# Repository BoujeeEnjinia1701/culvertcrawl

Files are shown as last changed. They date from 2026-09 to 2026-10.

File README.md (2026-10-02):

# CulvertCrawl

     

**Area:** Situational Field Hardware · **TRL:** 3 of 9 (proof of concept on paper) · **Value-engineering target:** $910 USD · **Difficulty:** 4 of 5

Tethered tracked crawler with a camera, lights and laser ring profiling that measures pipe deformation and blockage.

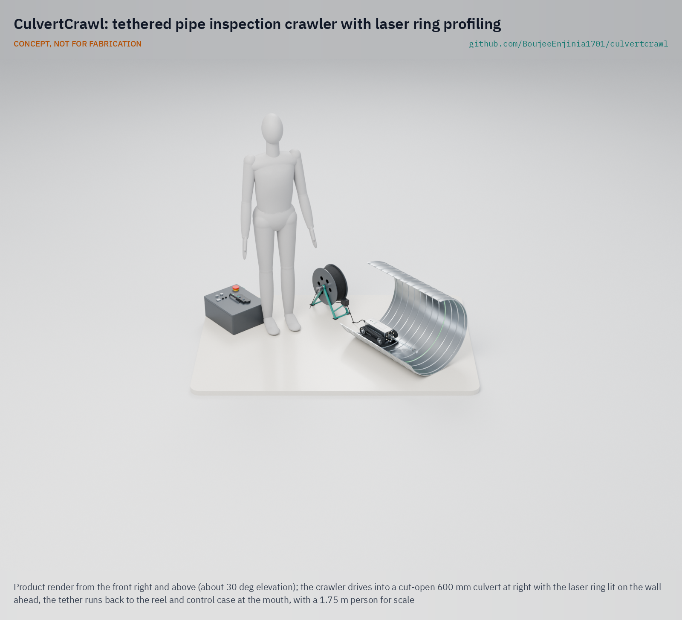
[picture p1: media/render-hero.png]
CulvertCrawl: tethered pipe inspection crawler with laser ring profiling, product render


[Exploded render](media/render-exploded.png) · [Detail render](media/render-detail.png) · [Interactive 3D model](media/viewer.html) · [Concept blueprint (PDF)](media/concept-blueprint.pdf) · [General arrangement (PDF)](cad/drawings/CVC-DWG-001.pdf) · [Calculations](docs/04-calcs/01-sizing.md) · [Prototype build plan](docs/05-build-plan.md) · [Design decisions](docs/06-design-decisions.md) · [Review note](docs/REVIEW.md)

## Concept rationale

A small tracked crawler on a surface-powered tether is the simplest way to see and measure the middle of a pipe that nobody should enter. Putting the battery, the power conversion and the processing at the surface keeps the vehicle small, cool and free of lithium cells, and a projected laser ring turns ordinary video into a cross-section measurement, which is the number owners and inspectors actually need for deflection, sag and sediment. Commercial crawlers already prove the principle; what is missing is a version priced and documented for the road crews, small towns and watershed groups who own most small culverts.

Open hardware fits that gap. Every part is a hobby or industrial catalog item, a machined box or a plate a local shop can cut, so a county shop or a student team can build, seal and repair it, and the video, profiles and observation logs use open formats that feed existing defect-coding practice. At TRL 3 this is a paper design checked by calculation; it is not yet a tested inspection tool.

## Burning platform

Flooding reaches road networks through their drainage. A World Bank global assessment of 2,564 cities in 177 countries found that a 1-in-100-year flood directly exposes 14.7 % of urban roads, yet causes 44.8 % of simulated trips to fail as the damage cascades through the network ([He, Rentschler and Avner, World Bank, 2022](https://blogs.worldbank.org/en/developmenttalk/mobility-and-resilience-global-assessment-flood-impacts-urban-road-networks)). Culverts are among the small, buried links in those networks, and their condition is hard to see from outside.

Public money is now flowing into culverts faster than owners can survey them. The United States set aside $200 million a year for fiscal years 2022 to 2026, $1 billion in all, for the National Culvert Removal, Replacement, and Restoration Grant program ([FHWA](https://highways.dot.gov/iija/fact-sheets/national-culvert-removal-replacement-and-restoration-grants-culvert-aop-program)). In Washington State alone, a federal court injunction issued in March 2013 requires the state to correct fish-barrier culverts under its highways; by June 2026 WSDOT had corrected 200 of them and reopened 705 miles (about 1,130 km) of salmon and steelhead habitat, with more funding still needed ([WSDOT](https://wsdot.wa.gov/construction-planning/protecting-environment/fish-passage/federal-court-injunction-fish-passage)). Choosing which pipes to fix first depends on knowing their condition.

## Where it could be used

### By industry

| Industry | Use |
| --- | --- |
| Road and highway maintenance | Check cross-drain and driveway culverts before resurfacing, after floods and when a sinkhole appears |
| Municipal stormwater | Inventory the condition of small storm drains and outfalls to plan replacements |
| Civil construction quality assurance | Measure deflection of newly installed plastic pipe before a road is paved over it |
| Environmental and fisheries surveys | Look for blockages, perched outlets and internal barriers in fish-passage culverts |
| Rail, forestry and farm roads | Inspect the many small culverts under tracks, logging roads and field access routes |
| Engineering education | An open platform for teaching robotics, sealing, optics and inspection practice |

### By country or region

| Country or region | Why it matters there |
| --- | --- |
| United States | Florida DOT requires laser-profile video inspection of new pipe of 48 in or less and replaces pipe deflected 5 % or more ([FDOT Section 430](https://fdotwww.blob.core.windows.net/sitefinity/docs/default-source/specifications/by-year/2008/july-2008/workbook/ss4300000.pdf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)); Washington State is correcting fish-barrier culverts under a federal injunction ([WSDOT](https://wsdot.wa.gov/construction-planning/protecting-environment/fish-passage/federal-court-injunction-fish-passage)) |
| United Kingdom | More than one million culverts and outfalls, which can completely restrict flow, are often costly to maintain and need ongoing assessment for sedimentation and blockage ([CIRIA and Environment Agency, *Culvert, screen and outfall manual*, via GOV.UK](https://www.gov.uk/flood-and-coastal-erosion-risk-management-research-reports/culvert-screens-and-outfall-manual)); councils such as Devon note that culverting can worsen flood risk and raise maintenance needs ([Devon County Council](https://www.devon.gov.uk/floodriskmanagement/land-drainage-consent/culvert-guidance/)) |
| Cambodia and Southeast Asia | The World Bank and GFDRR support climate-resilient rural road programs because flooded rural roads cut critical access for rural communities ([GFDRR](https://www.gfdrr.org/en/feature-story/pathway-resilient-rural-roads-cambodia)) |
| India | About 783,700 km of rural road had been completed under the Pradhan Mantri Gram Sadak Yojana by August 2025, and contractors are now paid for maintenance on the condition of each road's cross-drainage works among other assets ([Press Information Bureau, Government of India](https://static.pib.gov.in/WriteReadData/specificdocs/documents/2025/sep/doc2025914636101.pdf)) |
| Mali and Sudan | The World Bank global assessment found that more than half of simulated urban trips fail in these countries even in floods of lower intensity, so small drainage links matter early ([World Bank, 2022](https://blogs.worldbank.org/en/developmenttalk/mobility-and-resilience-global-assessment-flood-impacts-urban-road-networks)) |

## What sparked the idea

The starting point was a construction specification. Since at least 2008 the Florida Department of Transportation's Standard Specifications, Section 430, have required contractors to inspect newly installed pipe of 48 in (1,200 mm) or less with "low barrel distortion video equipment with laser profile technology," to report deflection and diameter, and to replace pipe deflected 5 % or more ([FDOT Section 430, Rev 12-7-07](https://fdotwww.blob.core.windows.net/sitefinity/docs/default-source/specifications/by-year/2008/july-2008/workbook/ss4300000.pdf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)). The same clause lets the engineer waive the requirement for side drains and cross drains short enough to inspect from each end. That pairing shows both halves of the design: laser ring profiling is already the accepted way to measure a buried pipe, while short culverts, and the older pipes that no contract covers, are still judged from the ends. CulvertCrawl aims to put that measurement within reach of the crews who look after those pipes for the rest of their service lives.

## Problem

Small culverts and drains are hard to inspect without confined-space entry. Pipes of 300 to 900 mm (12 to 36 in) are too small or too hazardous to walk through, so most are judged from the ends, and commercial CCTV crawlers are priced for sewer contractors, not the road crews and small owners who look after most culverts.

Problem statement: [docs/01-problem.md](docs/01-problem.md)

## Concept

Tethered tracked crawler with a camera, lights and laser ring profiling that measures pipe deformation and blockage. A 6.6 kg crawler drives into the pipe on a 60 m tether carrying 48 V DC and Ethernet; a laser ring projected 300 mm ahead of a fisheye camera gives a cross-section every 6 mm, from which the operator's laptop reports diameter, ovality and sediment depth against distance. The first output is a deflection report; observations are logged in NASSCO PACP vocabulary, and FHWA condition ratings come later. The TRL 3 calculations ([CVC-CAL-001](docs/04-calcs/01-sizing.md)) give 6.4 h per charge, about 75 m of reach driving uphill in a flooded pipe, and profile accuracy within 1 % of diameter from 300 to 900 mm (0.97 % at 900 mm, a thin margin). The wet reach depends on track friction under water, which only a test can settle. All figures are calculated estimates.

Full design precis: [docs/02-concept.md](docs/02-concept.md) · Requirements: [docs/03-requirements.md](docs/03-requirements.md) · Calculations: [docs/04-calcs/01-sizing.md](docs/04-calcs/01-sizing.md) · General arrangement: [cad/drawings/CVC-DWG-001.pdf](cad/drawings/CVC-DWG-001.pdf) · Model: [cad/src/model.py](cad/src/model.py)

## Key components

- Sealed aluminium hull with tracked chassis
- Self-locking worm gear motors (2)
- Waterproof fisheye camera behind a dome port
- LED ring light
- Class 2 laser ring projector (laser diode and conical mirror)
- 60 m hybrid tether on a reel with slip ring and payout counter
- Raspberry Pi 4 in the crawler
- Surface control box with LiFePO4 battery, 48 V boost and emergency stop

The priced bill of materials is in [bom/bom.csv](bom/bom.csv). Value-engineering target: $910 (a hypothetical control target, not a limit). Estimated cost of the constructable design: $1,034 ($124 over the target), because the parts that make the design buildable added $128. Cost drivers and savings worth trying are in the [design decisions register](docs/06-design-decisions.md).

## Building the prototype

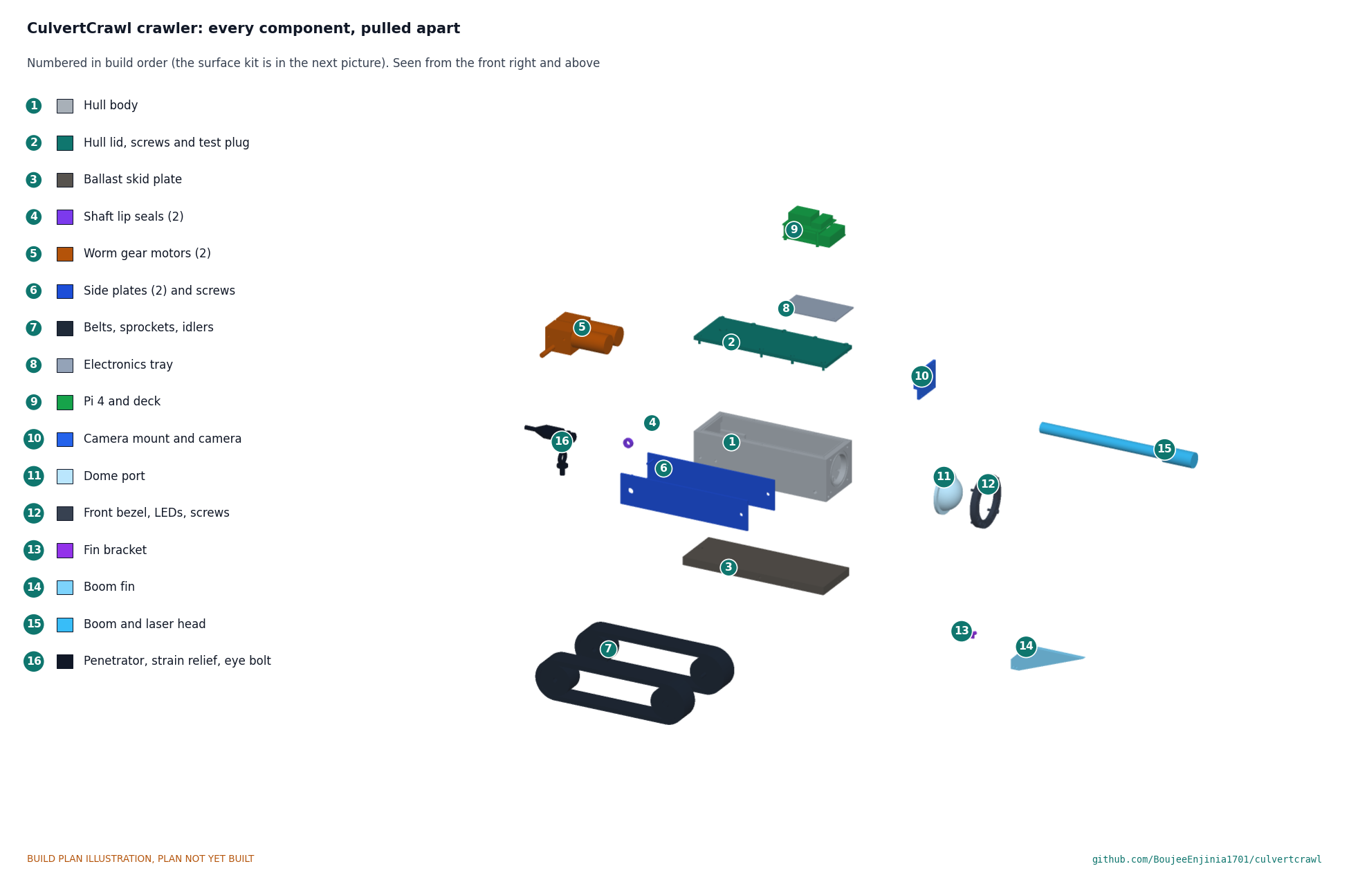
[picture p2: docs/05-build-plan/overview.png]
CulvertCrawl crawler: every component pulled apart and numbered in build order


The [prototype build plan](docs/05-build-plan.md) (CVC-BLD-001) shows, in pictures, how to make each component of the crawler, the tether reel and the surface box and put them together in 23 steps; nothing has been built yet. The hull, lid and front bezel are machined aluminium, the ballast plate is cut steel, the side plates, brackets, reel frames and box panel are cut from sheet and bar, the laser boom, fin and window are clear acrylic, and the motors, tracks, camera, electronics, tether and slip ring are bought. Writing the plan made the design buildable: a rim and pads inside the hull, side plates that tie the hull to the ballast plate, a bezel that clamps the dome, a fin that carries the laser boom, an eye bolt for the tether's strength member, a reel frame with bearings and a drop-in chassis for the surface box (CVC-DDR-003, open for Amish's review). Every picture is drawn from the model, and the model checks that each part touches what it should and clears what it should not.

## Repository layout

| Folder | Contents |
| --- | --- |
| `docs/` | Problem, concept, requirements, calculations and design decisions |
| `cad/src/` | build123d Python source, the source of truth for all geometry |
| `cad/step/`, `cad/stl/` | Exported models for FreeCAD, other CAD tools and printing |
| `cad/drawings/` | 2D sketches and dimensioned drawings |
| `bom/` | Bill of materials |
| `electronics/` | KiCad schematics and PCB layouts |
| `firmware/` | Microcontroller code |
| `media/` | Renders, perspectives and photos |
| `build-log/` | Dated prototyping notes |

## Documentation

Controlled documents follow the portfolio [documentation standard](.kit/STANDARDS.md). Each carries a document ID (CVC-PRC-001 for the precis), a version and a revision history. Branded PDFs are built with `python .kit/render.py` and attached to GitHub Releases when a document is tagged, for example `CVC-PRC-001/v1.0`.

## Credits

Designed by Amish Chadha. See [CONTRIBUTORS.md](CONTRIBUTORS.md) for roles. To cite this design, use [CITATION.cff](CITATION.cff) (GitHub shows it as "Cite this repository").

AI assistance (Claude) was used to accelerate concept renders, prototype documentation and first-pass sizing calculations. Design direction and all decisions are Amish Chadha's, recorded in this repository's decision records (`docs/decisions/`).

## Licenses

- **Hardware** (CAD, drawings, BOM, electronics): [CERN-OHL-S v2](LICENSE)
- **Software** (firmware, scripts, notebooks): [MIT](LICENSE-SOFTWARE)

A project of the [Design Molecule](https://designmolecule.com) lab.

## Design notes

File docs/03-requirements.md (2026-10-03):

---
doc_id: CVC-REQ-001
title: CulvertCrawl requirements
project: CulvertCrawl
doc_type: Requirements
version: "0.8"
status: Draft
date: '2026-10-02'
author: Amish Chadha
license: CERN-OHL-S-2.0
revisions:
- version: "0.1"
  date: '2026-09-24'
  author: Amish Chadha
  change: Initial scaffold
- version: "0.2"
  date: '2026-09-25'
  author: Amish Chadha
  change: First measurable requirements for TRL 2, with first-order status against the concept
- version: "0.3"
  date: '2026-09-25'
  author: Amish Chadha
  change: TRL 3. Record Amish's 2026-09-25 decisions (CVC-DDR-001); R12 target $900; status from CVC-CAL-001
- version: "0.4"
  date: '2026-09-25'
  author: Amish Chadha
  change: Recommendations accepted by Amish (DDR-002)
- version: "0.5"
  date: '2026-09-26'
  author: Amish Chadha
  change: Budget approved by Amish
- version: "0.6"
  date: '2026-09-30'
  author: Amish Chadha
  change: Status from CVC-CAL-001 v0.4 after the design for construction (CVC-DDR-003); R12 met to not met
- version: "0.7"
  date: '2026-10-01'
  author: Amish Chadha
  change: Budget treated as a value-engineering target
- version: "0.8"
  date: '2026-10-02'
  author: Amish Chadha
  change: Laptop software outputs specified in the decided order (R5 deflection report first, R13 observation log second, FHWA ratings later; CVC-DEC-001)
---

# CulvertCrawl requirements

These requirements were checked by calculation at TRL 3 in CVC-CAL-001 v0.5 (`docs/04-calcs/01-sizing.md`). Version 0.6 follows the constructable design of CVC-DDR-003 (2026-09-30, open for Amish's review): no target changed, but the parts added for construction put the priced BOM at $1,034, so R12 is over the value-engineering target by $124 (a hypothetical control target of $910, not a limit). Earlier status follows. After the design changes Amish accepted on 2026-09-25 (CVC-DDR-002: 0.46 kg more ballast and the laser ring plane moved to 300 mm ahead), R2 and R5 are met on paper with thin margins, and R12 was within the $910 value-engineering target, which Amish set on 2026-09-26 to match the $906 priced BOM (CVC-DDR-002). No requirement is not met. Targets are still to be validated with users (see CVC-PRB-001). The pipe range in R1 and R5 was decided by Amish on 2026-09-25 (CVC-DDR-001); the R12 target was first set on 2026-09-25 (CVC-DDR-001) and moved to $910 on 2026-09-26 (CVC-DDR-002). The status column is a calculated estimate, not a measurement.

The **design case** used throughout is a straight 600 mm (24 in) corrugated steel culvert, 50 m long, on a 5 % slope, with a wet silt invert and up to 150 mm of water flowing at 0.5 m/s. Unless stated, the crawler enters at the outlet and drives uphill against the flow, the worst direction. In 150 mm of water the 106 mm crawler is fully submerged. As operating guidance (CVC-DDR-002), crews should enter flooded pipes from the upstream end where access allows; the design case keeps the worst direction.

## Requirements

| ID | Requirement | Target | Verification (TRL 3 or later) | Status (CVC-CAL-001) |
| --- | --- | --- | --- | --- |
| R1 | Fit the target pipes | Drive in round pipes of 300 to 900 mm (12 to 36 in) inside diameter; crawler no wider than 180 mm and no taller than 140 mm | Model check in 300 mm and 900 mm pipe sections | Met (170 x 106 mm, 611 mm long; 50 mm or more clearance) |
| R2 | Reach | Drive 50 m into the design case pipe and back, pulling the tether, with 20 % traction reserve | Traction and tether drag calculation; later pull test | Met on paper (75 m wet and uphill; 64 m dry uphill; more than 100 m downhill); about 23 m if submerged track friction is 0.45 |
| R3 | Recover without entry | Crawler can be pulled out by the tether if disabled; tether break strength 1 kN or more, at least 5 times the worst stuck-pull estimate | Tether datasheet; pull calculation | Met (about 59 N locked-track pull, factor 17; strength member on an eye bolt in the ballast plate); jamming by debris not calculable |
| R4 | Video | 1080p video at 25 frames per second or more, live at the operator and recorded, with distance and time overlay; lighting to show the far wall of a 900 mm pipe | Camera and link budget; later image review | Met on paper (25 fps from a 50 fps stream, 53 % link use, about 370 lx); Pi 4 throughput not verifiable at TRL 3 |
| R5 | Cross-section profile | Measure the wall profile in the ring plane and report mean diameter and ovality (deflection) to within 1 % of nominal diameter, every 0.1 m of travel or less; the laptop software's first output is this deflection report (decided 2026-10-02) | Error budget; later calibration pipes | Met on paper: 0.25 % at 300 mm, 0.57 % at 600 mm, 0.97 % at 900 mm (thin margin), with the boom fin's shadow; spacing 6 mm |
| R6 | Locate observations | Distance from the pipe mouth within 1 % or 0.2 m, whichever is larger; pitch and roll within 1 degree | Encoder and IMU datasheets | Not verifiable at TRL 3 (tether slack and wheel slip) |
| R7 | Drive in water and silt | Operate in 150 mm of water flowing at 0.5 m/s over a silt invert; survive full submersion to 1 m for 30 min (IP68 target) | Drag and buoyancy calculation; later tank test | At risk: holds in the flow on paper; IP68 not verifiable at TRL 3 |
| R8 | Climb | Hold position on a 5 % slope with power off; cross a 40 mm step or joint offset | Worm gear self-locking; track geometry | At risk: hold met; step limit between 35 and 53 mm |
| R9 | Endurance | 4 h or more of mixed driving and profiling per charge | Energy budget | Met (6.4 h nominal, 5.1 h derated) |
| R10 | Portable and quick | Whole kit 25 kg or less, no single case over 10 kg, carried by two people in one trip; set up from vehicle to driving in 10 min or less | Mass estimate; setup sequence | Met on mass (22.2 kg; heaviest item 7.8 kg, the reel with tether); setup time not verifiable at TRL 3 |
| R11 | Electrical and laser safety | Tether and crawler 48 V DC nominal (below the 60 V DC extra-low-voltage limit), fused, with overcurrent cutoff and an emergency stop at the surface; laser Class 2 or lower under IEC 60825-1 | Design review | Met by design (10 A and 2 A fuses, 1.5 A cutoff) |
| R12 | Affordable | Full kit (crawler, 60 m tether, reel, surface box) $910 or less in parts, operator laptop excluded (value-engineering target set by Amish, 2026-09-26; was $900) | Priced BOM (`bom/bom.csv`) | **Over the value-engineering target by $124** ($1,034 against $910, after the parts added for construction in CVC-DDR-003). Prices are indicative |
| R13 | Open and repairable | Common parts; every tether and module joint pluggable; open file formats (MP4 video, CSV profiles, JSON observation log with PACP-style codes); the laptop software's second output is the observation log in NASSCO PACP vocabulary, and FHWA condition ratings come later (decided 2026-10-02) | Design review | Met by design |

## Requirements not met or at risk

- **R12 is over the value-engineering target by $124** (estimated $1,034 against a $910 target). The parts that make the design buildable (CVC-DDR-003) added $128 to the $906 that the target was set to match on 2026-09-26. Cost drivers and savings worth trying are in the Value engineering section of the design decisions register.
- **R2 (reach) is met on paper.** The constructable crawler is 6.63 kg (3.77 kg net when submerged) and reaches 75 m driving uphill against 0.5 m/s flow (52 m in v0.5, 39 m before CVC-DDR-002). The result is still very sensitive to track friction under water: at 0.45 it falls to about 23 m. Measuring that friction is TRL 4 work and is on hold. Entering flooded pipes from the upstream end is now operating guidance.
- **R5 at 900 mm is met on paper with a thin margin.** With the ring plane 300 mm ahead (was 200 mm), the top of a 900 mm pipe is 70.1 degrees off the camera axis (was 76.5 degrees) and the vertical diameter error is 0.97 % (was 1.59 %).
- **R7 and R8 are at risk:** seals (IP68) and the 40 mm step cannot be settled on paper.
- **R6 cannot be verified at TRL 3.**

## Assumptions

- Track-to-silt friction coefficient about 0.6 and track motion resistance about 0.15 of weight; tether-to-pipe friction coefficient about 0.5.
- Crawler mass about 6.6 kg with ballast (3.77 kg net when submerged); tether about 55 g/m; both are estimates until parts are selected.
- 50 m reach covers most road crossings; 60 m of tether allows 10 m from the reel to the mouth.
- A 1 % profile accuracy resolves the roughly 5 % deflection limit used for plastic pipe acceptance with a 5 to 1 margin.
- The operator's own laptop runs the viewing and profiling software. Its outputs come in this order: the deflection report (R5), then the observation log in NASSCO PACP vocabulary (R13), with FHWA condition ratings later.

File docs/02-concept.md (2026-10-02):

---
doc_id: CVC-PRC-001
title: CulvertCrawl design precis
project: CulvertCrawl
doc_type: Design precis
version: "0.8"
status: Draft
date: '2026-10-02'
author: Amish Chadha
license: CERN-OHL-S-2.0
revisions:
- version: "0.1"
  date: '2026-09-24'
  author: Amish Chadha
  change: Initial scaffold
- version: "0.2"
  date: '2026-09-25'
  author: Amish Chadha
  change: Populate to TRL 2 (architecture, profiling principle, first-order numbers, safety, media)
- version: "0.3"
  date: '2026-09-25'
  author: Amish Chadha
  change: TRL 3. Record Amish's 2026-09-25 decisions (CVC-DDR-001); numbers checked against CVC-CAL-001; camera at 50 fps with circular fisheye; fuse split; model and drawing CVC-DWG-001
- version: "0.4"
  date: '2026-09-25'
  author: Amish Chadha
  change: Recommendations accepted by Amish (DDR-002)
- version: "0.5"
  date: '2026-09-26'
  author: Amish Chadha
  change: Budget approved by Amish ($910, CVC-DDR-002); cost figures restated against it
- version: "0.6"
  date: '2026-09-30'
  author: Amish Chadha
  change: Constructable design (CVC-DDR-003); numbers from CVC-CAL-001 v0.4; build plan CVC-BLD-001 and design decisions register CVC-DEC-001
- version: "0.7"
  date: '2026-10-01'
  author: Amish Chadha
  change: Budget treated as a value-engineering target
- version: "0.8"
  date: '2026-10-02'
  author: Amish Chadha
  change: 'Decisions of 2026-10-02 (CVC-DEC-001): design for construction accepted; boom on two bolts for the prototype; output order (deflection report first)'
---

# CulvertCrawl design precis

CulvertCrawl is a small tracked crawler, about 611 x 170 x 106 mm and 6.6 kg, that drives into a 300 to 900 mm culvert on a 60 m tether while an operator watches live video on a laptop at the pipe mouth. A green laser ring projected onto the pipe wall 300 mm ahead of a fisheye camera gives a cross-section every 6 mm of travel, from which the software reports diameter, ovality (deflection) and sediment depth against distance. The TRL 3 calculations (CVC-CAL-001 v0.5) give 6.4 h per charge, 75 m of reach when the crawler drives submerged and uphill against the flow, profile accuracy of 0.25 %, 0.57 % and 0.97 % of diameter in 300, 600 and 900 mm pipe, and an estimated parts cost of $1,034 against the $910 value-engineering target. On 2026-09-30 the design was made constructable (CVC-DDR-003, open for Amish's review): every part can now be made and fixed, which made the crawler heavier (better reach) and added $128 of parts, so R12 is $124 over its $910 value-engineering target. The prototype build plan is CVC-BLD-001 (`docs/05-build-plan.md`); open decisions are in CVC-DEC-001 (`docs/06-design-decisions.md`). All numbers are calculated estimates, not measurements.

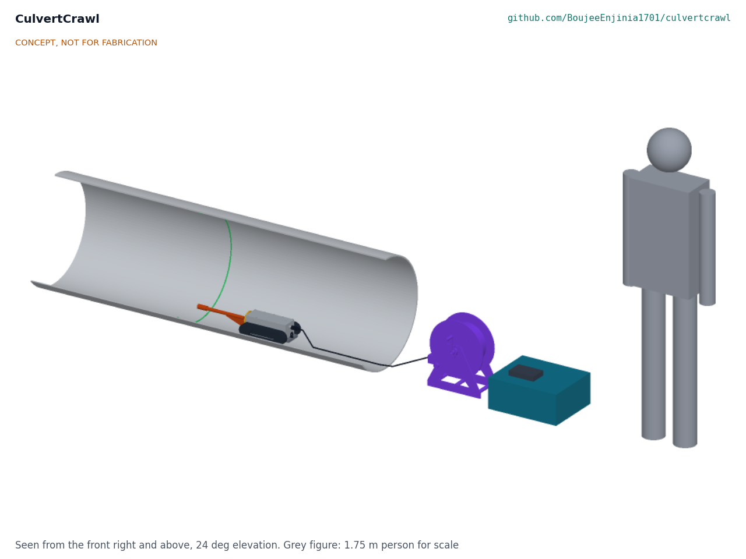
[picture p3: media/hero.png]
Hero render


*Figure 1. CulvertCrawl in a sectioned 600 mm culvert, with the tether reel and surface control box at the mouth and a 1.75 m person for scale. The green line is the projected laser ring (illustrative).*

## How it works

1. **Deploy.** Two people carry the crawler, the tether reel and the surface box from the vehicle to the culvert mouth. The operator connects a laptop and gamepad to the surface box, sets the payout counter to zero at the mouth and lowers the crawler onto the invert.
2. **Power and data.** A 12.8 V LiFePO4 battery in the surface box feeds a boost converter that puts 48 V DC on two power conductors in the tether. Two twisted pairs in the same tether carry 100 Mbit/s Ethernet between the laptop and the crawler. A slip ring in the reel hub lets the drum turn while connected. The surface box holds a 10 A fuse at the battery, a 2 A fuse on the 48 V output, a 1.5 A overcurrent cutoff and a latching emergency stop that kills tether power.
3. **Drive.** Inside the sealed aluminium hull, a Raspberry Pi 4 runs the motor driver for two self-locking worm gear motors, one per rubber track. The operator drives with the gamepad at about 0.15 m/s while surveying. The worm gears hold the crawler on a slope with power off.
4. **See.** A 12 MP camera with a 180 degree circular fisheye lens looks forward through an acrylic dome, lit by a ring of eight 1 W LEDs. The Pi encodes the LED frames as 1080p H.264 video at 25 frames per second in hardware and streams it to the laptop, which records it with distance, time and attitude overlaid. Distance comes from the payout counter at the reel, cross-checked by track odometry; pitch and roll come from an IMU in the hull.
5. **Measure.** The camera runs at 50 frames per second; the LEDs light alternate frames for video and the laser ring is captured on the frames between. A Class 2 laser diode at the tip of a clear boom shines onto a 90 degree conical mirror, which spreads the beam into a thin disc of light perpendicular to the crawler axis, 300 mm ahead of the lens. Where the disc meets the wall it draws a bright ring. On the laser frames the LEDs dim and the software finds the ring in the image. Because the ring plane is fixed relative to the camera, each ring pixel defines a ray that meets the plane at exactly one point, so the wall is triangulated in 3D even when the crawler is well below the pipe axis. The software fits a circle and an ellipse to each ring, and reports mean diameter, ovality, and the height of any flat sediment or water surface across the invert, every 6 mm of travel at survey speed.
6. **Choose the entry end.** In flooded pipes, enter from the upstream end and drive with the flow where access allows (operating guidance, CVC-DDR-002); reach driving upstream against the flow is the thinnest margin in the design.
7. **Recover.** The crawler reverses out while the operator winds the reel. If it stalls or loses power, the tether's aramid strength member lets the crew pull it out by hand; nobody enters the pipe.

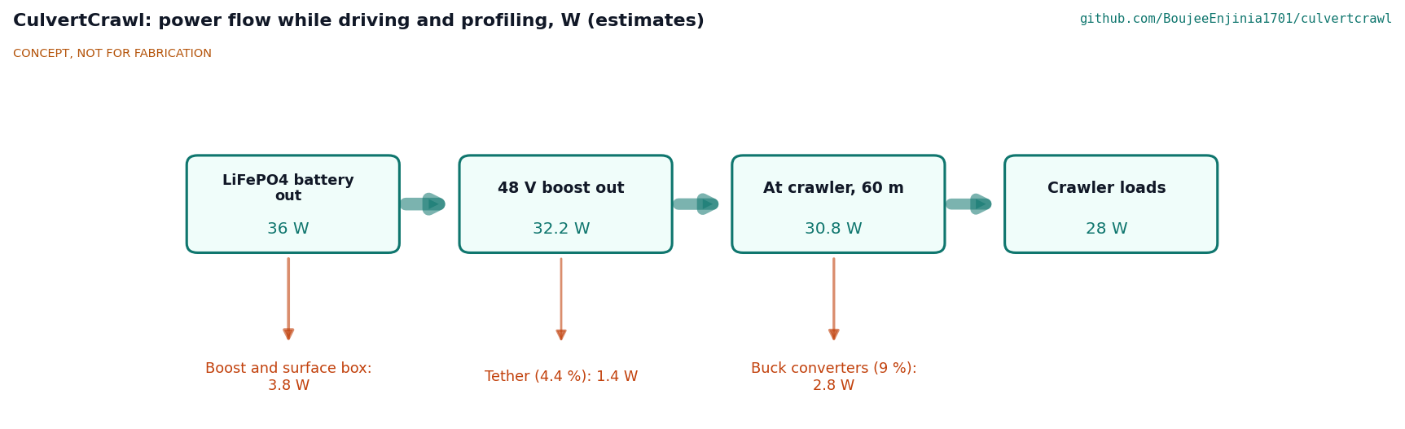
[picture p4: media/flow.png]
Power flow


*Figure 2. Power flow while driving and profiling, in watts, from CVC-CAL-001. All values are estimates.*

## Main components

Numbers match the exploded view (Figure 3) and `bom/bom.csv`.

| # | Component | Proposed choice | Notes |
| --- | --- | --- | --- |
| 1 | Sealed hull and lid | 6061 aluminium body 240 x 88 x 74 mm machined from a block, 4 mm walls, 10 mm front wall, inner rim with the lid O-ring and ten M4 screws, flush 6 mm lid, IP68 penetrator, pressure-test plug (about 1.26 kg) | Leak check by vacuum or low pressure before each use |
| 2 | Track modules (pair) | Rubber belts 36 mm wide over 70 mm sprockets, outer edges 170 mm apart; made 3 mm side plates tie the hull to the ballast plate | Outer track edges bear on the curved invert |
| 3 | Worm gear motors (2) | 12 V, about 80 rpm output, rated 1 N·m or more (0.67 N·m needed), self-locking, Hall encoders, double lip shaft seals | Shaft seals are the main leak path |
| 4 | Electronics stack | Raspberry Pi 4 Model B 2 GB, dual motor driver, 48 to 12 V and 12 to 5 V converters, IMU, leak sensor | Pi 4 chosen for its hardware H.264 encoder |
| 5 | Fisheye camera and dome port | 12 MP IMX708 module with M12 mount at 2304 x 1296 and 50 fps; 180 degree circular fisheye with the image circle inside the sensor height; 60 mm acrylic dome centered on the lens | Dome keeps the wide field of view if the port is wet |
| 6 | LED ring light | 8 x 1 W high-CRI white LEDs, about 800 lm (estimate), dimmable, potted in a machined front bezel that also clamps the dome | Dimmed on laser frames |
| 7 | Laser ring projector | Class 2 (1 mW or less) 520 nm diode, 90 degree conical mirror behind a clear window, ring 300 mm ahead of the lens (200 mm before CVC-DDR-002); clear boom on a clear fin bolted to the ballast plate | Held by two M3 bolts at the fin bracket for the prototype; a tool-free clamp is decided after the first pipe trials (decided 2026-10-02) |
| 8 | Ballast skid plate | Steel 255 x 88 x 14 mm, about 2.45 kg, square nose, 8 mm above the track contact line; carries the side plates, fin bracket and the tether's eye bolt (230 x 80 x 14 mm with a lip before CVC-DDR-003) | Raises traction and protects the hull; enlarged for R2 (CVC-DDR-002) |
| 9 | Tether | 60 m hybrid: 2 twisted pairs plus 2 x 0.75 mm² power, aramid member, PU jacket about 7 mm, about 55 g/m (estimate) | Also the recovery line |
| 10 | Tether reel | 320 mm flanged reel, A-frame, crank and brake, Ethernet-rated slip ring, payout encoder wheel | Payout counter gives distance |
| 11 | Surface control box | Rugged case; 12.8 V 20 Ah LiFePO4 with BMS; 12 to 48 V boost; 10 A and 2 A fuses; emergency stop; 1.5 A overcurrent cutoff | Laptop connects by Ethernet |
| 12 | Operator gamepad | USB gamepad | Laptop is the user's own |

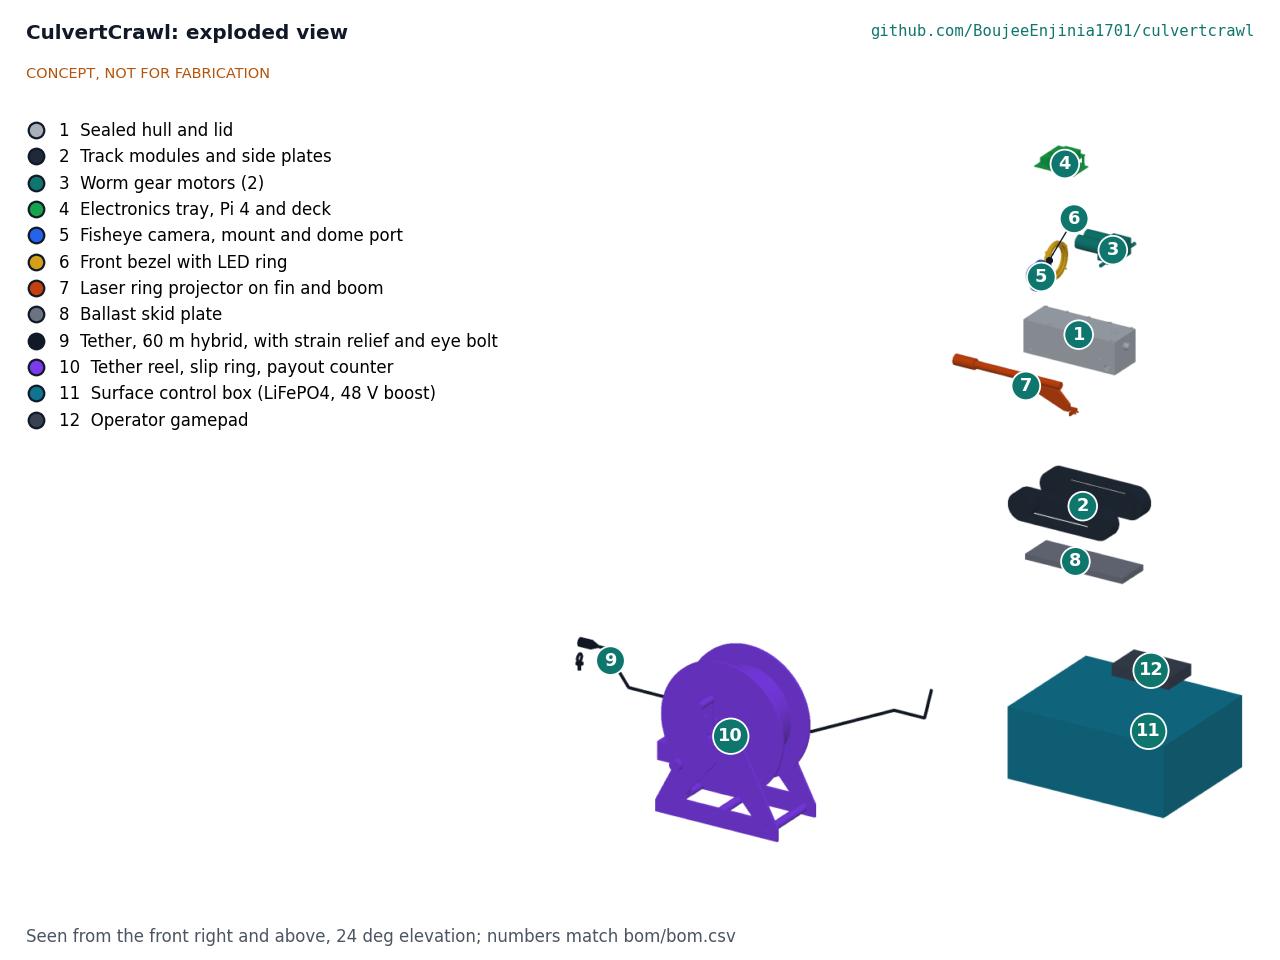
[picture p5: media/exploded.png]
Exploded view


*Figure 3. Exploded view with numbered callouts matching the BOM. The surface kit (9 to 12) is shown displaced in front of the crawler.*

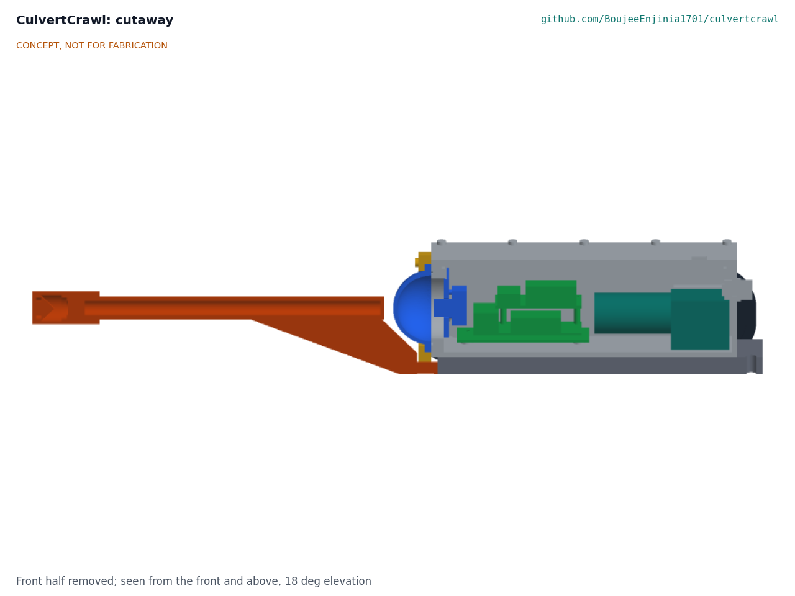
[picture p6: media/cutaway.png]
Cutaway


*Figure 4. Cutaway of the crawler along its axis: dome and camera, electronics stack, worm gear motors at the rear, ballast plate underneath, and the laser boom ahead of the dome.*

The parametric build123d model is `cad/src/model.py` (STEP and STL in `cad/step/` and `cad/stl/`), and the general arrangement is drawing CVC-DWG-001 Rev P3 (`cad/drawings/CVC-DWG-001.pdf`).

## Key numbers (from CVC-CAL-001 v0.5)

This section summarizes the TRL 3 calculation note, CVC-CAL-001 (`docs/04-calcs/01-sizing.md`); every value is printed by `docs/04-calcs/sizing.py`. The design case is a straight 600 mm corrugated steel culvert, 50 m long, on a 5 % slope, with a wet silt invert and 150 mm of water at 0.5 m/s.

### Mass and buoyancy

| Item | Value | Basis |
| --- | --- | --- |
| Crawler | 6.63 kg | Hull and lid 1.26 kg, ballast 2.45 kg and the other made parts from model volumes; bought parts estimated |
| Displaced volume | 2.87 L | Hull envelope, dome, bezel, tracks, ballast, boom, fin |
| Net weight fully submerged | 3.77 kg | 57 % of the dry normal load |
| Design case | Fully submerged | 138 mm of water above the track contact line against a 106 mm crawler |
| Whole kit | 22.2 kg; heaviest item 7.8 kg (reel with tether) | R10 met on mass |

### Traction and reach

Reach is the tether length whose drag uses up the traction left after track resistance, grade and water drag, with 20 % traction reserve. Driving uphill also lifts the tether up the grade, which the TRL 2 estimate left out.

| Case | Reach | Requirement |
| --- | --- | --- |
| Dry, uphill | 64 m | Met |
| Dry, downhill | 106 m | Met |
| Design case: submerged, uphill against 0.5 m/s flow | **75 m** | Met on paper (52 m before CVC-DDR-003) |
| Design case: submerged, downhill with the flow | 216 m | Met |

The wet result is very sensitive to track friction under water: at 0.45 instead of 0.6, wet uphill reach falls to about 23 m. Measuring that friction is TRL 4 work, on hold. Sprocket torque at the dry traction limit is 0.84 N·m per motor, within the 1 N·m motor rating; top speed is 0.29 m/s.

### Power and endurance

| Quantity | Value |
| --- | --- |
| Crawler loads; crawler input | 28.0 W; 30.8 W |
| Tether loop resistance (2 x 60 m of 0.75 mm²) | 3.12 Ω |
| Tether current; voltage at the crawler; copper loss | 0.67 A; 45.9 V; 1.40 W (4.4 %) |
| Peak: tether current; drop | 1.25 A; 3.9 V |
| Battery output | 36.0 W |
| **Endurance** | **6.4 h nominal; 5.1 h derated** (R9 met) |

At 24 V the tether would lose 8.24 W. The peak battery current of 5.4 A exceeds the 5 A fuse listed at TRL 2, so the fuses are now 10 A at the battery and 2 A on the 48 V output.

### Laser ring profiling

The ring plane sits 300 mm ahead of the dome center (200 mm before CVC-DDR-002). With the camera 70 mm above the invert of a 900 mm pipe, the top of the pipe is 70.1 degrees off the camera axis (76.5 degrees at 200 mm), beyond the vertical field of a 160 degree lens on a 16:9 frame. The design therefore uses a 180 degree circular fisheye inside the 1296 px sensor height (0.139 degree per pixel). A Monte Carlo of ring centroid noise, lens model residual, ring plane tilt and distance, and crawler yaw gives, at the 95th percentile:

| Pipe | Vertical diameter error | R5 (1 % of diameter) |
| --- | --- | --- |
| 300 mm | 0.25 % | Met |
| 600 mm (150 mm of water) | 0.57 % | Met |
| 900 mm (150 mm of water) | 0.97 % | Met, thin margin (1.41 % with the ring plane at 200 mm) |

These include the shadow of the clear fin that carries the boom (CVC-DDR-003): it hides a thin strip of the ring at the invert, 6.4 % of the ring in 300 mm pipe.

The longer boom puts the cone mirror about 300 mm ahead of the tracks, which matters in bends and at offset joints (see the open removable-boom question). The profile covers only the wall above any water surface, because the light refracts at the water line; the software reports the water or sediment chord instead. At 25 profiles per second, the spacing is 6 mm at 0.15 m/s. A 1 mW ring gives about 272 signal electrons per pixel on the wall of a 900 mm pipe, enough in a dark pipe.

### Cost

| Group | Cost | Requirement |
| --- | --- | --- |
| Crawler (items 1 to 8, 14, 15) | $481 | Bezel, side plates and other parts added for construction (CVC-DDR-003) |
| Tether, reel and surface kit (items 9 to 12) | $513 | Reel frame, bearings, counter reader, box chassis |
| Hardware and consumables (item 13) | $40 | |
| **Total** | **$1,034** | R12: **over the value-engineering target by $124** (target $910) |

The laptop is excluded.

## Key design choices

Amish decided items 1 to 8 of the TRL 2 review on 2026-09-25 by accepting the recommendations (CVC-DDR-001), and later the same day accepted the TRL 3 recommendations on reach, profiling and cost (CVC-DDR-002).

- **Tracks rather than wheels.** Tracks spread the load on silt and ride over corrugations and joint offsets. Decided by Amish, 2026-09-25: go with recommendation.
- **Power from the surface over the tether at 48 V DC, with no battery in the crawler.** Surface power keeps lithium cells out of the pipe and the crawler small. At 48 V the tether loses 4.4 %; at 24 V it would lose about six times as much. 48 V stays below the 60 V DC extra-low-voltage limit. Decided by Amish, 2026-09-25: go with recommendation.
- **Surface battery: 12.8 V 20 Ah LiFePO4 rather than a SwapCell pack.** A SwapCell-compatible input stays a later option; it would cite SwapCell interface v0.3, whose wake on a coded INTERLOCK loop needs no CAN host. Decided by Amish, 2026-09-25: go with recommendation.
- **Laser ring ahead of a fixed fisheye camera,** Class 2, 520 nm, rather than structured light, stereo or a pan-tilt head. Decided by Amish, 2026-09-25: go with recommendation.
- **Processing on the laptop.** The Pi streams video and sensor data; ring extraction and reports run on the operator's laptop. Decided by Amish, 2026-09-25: go with recommendation.
- **Pipe range 300 to 900 mm.** Kept, with the 900 mm case checked at TRL 3 (R5 not met at 900 mm). Decided by Amish, 2026-09-25: go with recommendation.
- **Value-engineering target $900.** Decided by Amish, 2026-09-25: go with recommendation. Superseded: target set to $910 to match the priced BOM, decided by Amish, 2026-09-26 (CVC-DDR-002).
- **Removable laser boom.** Held by two M3 bolts at the fin bracket for the prototype, so it comes off for repair; a tool-free clamp is decided after the first pipe trials. Decided by Amish, 2026-10-02 (CVC-DEC-001).
- **Output order.** The deflection report comes first; observations are logged in NASSCO PACP vocabulary second, and FHWA condition ratings come later. Decided by Amish, 2026-10-02 (CVC-DEC-001).
- **Heavier ballast plate for reach (R2).** 230 x 80 x 14 mm steel, 2.13 kg (was 1.67 kg), plus the operating guidance to enter flooded pipes from the upstream end. Decided by Amish, 2026-09-25: go with recommendation (CVC-DDR-002). Measuring submerged track friction is TRL 4 work, on hold.
- **Ring plane 300 mm ahead of the camera (R5).** Was 200 mm; the boom is 100 mm longer. Decided by Amish, 2026-09-25: go with recommendation (CVC-DDR-002).
- **Cost at $901.** The $1 overrun at CVC-CAL-001 v0.1 is accepted as within pricing uncertainty, to revisit when real quotes exist. Decided by Amish, 2026-09-25: go with recommendation (CVC-DDR-002). The $5 added by the two changes above is within the $910 value-engineering target Amish set on 2026-09-26 (CVC-DDR-002).
- **Design for construction.** On 2026-09-30, under Amish's instruction to make the design physically buildable, every part was given a way to be made and fixed (CVC-DDR-003): hull rim and drive pads, side plates, bezel, boom fin, laser window, ballast plate resized, eye bolt, reel frame and box chassis. Accepted by Amish, 2026-10-02 (CVC-DDR-003).
- **Camera at 50 frames per second with a circular fisheye.** A TRL 3 engineering choice so that video (R4) and profiling (R5) are both met from one camera; recorded in CVC-CAL-001.

## Safety

> **Safety:** CulvertCrawl is used at roadside ditches, next to flowing water and at the mouth of a confined space. It carries a lithium battery, 48 V DC on a long cable, a laser and moving tracks. The most important rule is that nobody enters the pipe, including to recover a stuck crawler.

- **Confined space.** A culvert is a confined space and may be a permit-required confined space under OSHA 29 CFR 1910.146 ([osha.gov](https://www.osha.gov/laws-regs/regulations/standardnumber/1910/1910.146)). The purpose of CulvertCrawl is to avoid entry. Never enter or lean into a pipe to free the crawler; pull it out by the tether, or leave it and call a qualified entry team.
- **Hazardous atmospheres.** The crawler is not intrinsically safe and is not rated for flammable atmospheres. Do not use it in sanitary sewers, in storm drains that may receive sewage or fuel, or anywhere methane or other flammable gas may be present. In any enclosed drain, check the air at the mouth with a four-gas monitor before and during work.
- **Traffic, water and banks.** Road culverts put crews on shoulders and steep, wet banks. Use temporary traffic control as the road owner requires (for example MUTCD Part 6 in the United States), high-visibility clothing and a second person as spotter. Do not work in fast or rising water; flash floods can arrive with little warning.
- **Lithium battery.** The surface box holds a 12.8 V 20 Ah LiFePO4 battery (about 256 Wh). Use a battery with a BMS, keep the 10 A battery fuse and the 2 A tether fuse, charge with a matched LiFePO4 charger on a non-combustible surface, and do not charge a battery that is damaged, swollen or has been in water.
- **Electrical.** 48 V DC on the tether is extra-low voltage, but a damaged tether in water can still corrode and short. The surface box has fuses, a 1.5 A overcurrent cutoff and a latching emergency stop; inspect the tether jacket before each use and retire damaged lengths.
- **Laser.** The projector must stay at Class 2 (1 mW or less, visible) under IEC 60825-1. Do not stare into the beam or look at it through optics; switch the laser off when the crawler is out of the pipe.
- **Moving parts and tether.** Tracks and sprockets can pinch fingers; the emergency stop removes drive power. Pull a stuck crawler out by hand only; the strength member is tied to an eye bolt in the ballast plate, so the pull never goes through the seal. Never tie the tether to a vehicle, which can exceed the 1 kN strength member and whip the cable. The reel crank can kick back under tether tension, so use the brake. Keep the tether clear of walkways to avoid trips.
- **Sharp edges and wildlife.** Rusted metal pipe has sharp edges at holes and seams. Wear cut-resistant gloves when handling the tether at the mouth, and watch for snakes, wasps and other animals in and near culverts.

## Open questions

- Reach in the wet, uphill design case is 52 m on paper but very sensitive to track friction under water; what is the real submerged friction on silt? (TRL 4 measurement, on hold.)
- Will double lip seals on the drive shafts hold IP68, or is a magnetic coupling or a sealed motor pod needed?
- Is a Class 2 laser bright enough near a sunlit mouth or on a reflective wall, or does the camera need a narrowband filter?
- Can a Pi 4 capture at 50 frames per second and run the H.264 and JPEG encoders at once?
- Should the laser boom be quick-release for tight or bent pipes? It comes off with two bolts for the prototype (decided 2026-10-02); a tool-free clamp is decided after the first pipe trials.

## References

- US Occupational Safety and Health Administration. 29 CFR 1910.146, *Permit-required confined spaces*; and 29 CFR 1926 Subpart AA, *Confined Spaces in Construction*.
- Federal Highway Administration. *Culvert Inspection Manual*. FHWA-IP-86-2, 1986.
- Federal Highway Administration. *Culvert Assessment and Decision-Making Procedures Manual*. FHWA-CFL/TD-10-005, 2010.
- ASTM D2321, *Standard Practice for Underground Installation of Thermoplastic Pipe for Sewers and Other Gravity-Flow Applications*.
- NASSCO. *Pipeline Assessment Certification Program (PACP)*. [nassco.org](https://www.nassco.org).
- Duran, O., K. Althoefer and L. D. Seneviratne. "State of the Art in Sensor Technologies for Sewer Inspection." *IEEE Sensors Journal* 2, no. 2 (2002).
- Duran, O., K. Althoefer and L. D. Seneviratne. "Automated Pipe Defect Detection and Categorization Using Camera/Laser-Based Profiler and Artificial Neural Network." *IEEE Transactions on Automation Science and Engineering* 4, no. 1 (2007).
- IEC 60825-1, *Safety of laser products, Part 1: Equipment classification and requirements*.
- IEC 60529, *Degrees of protection provided by enclosures (IP Code)*.

On 2026-09-25 the OSHA regulation, both FHWA manuals and both Duran papers were confirmed online by title, number and year (the 2007 paper at *IEEE Transactions on Automation Science and Engineering* 4, page 118). The ASTM D2321 deflection clause, NASSCO PACP, IEC 60825-1 and IEC 60529 were not rechecked.

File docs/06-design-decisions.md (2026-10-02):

---
doc_id: CVC-DEC-001
title: CulvertCrawl design decisions register
project: CulvertCrawl
doc_type: Design decisions register
version: "0.3"
status: Draft
date: '2026-10-02'
author: Amish Chadha
license: CERN-OHL-S-2.0
revisions:
- version: "0.1"
  date: '2026-09-30'
  author: Amish Chadha
  change: Register opened with the open decisions from the review note, the decision records and the build plan work
- version: "0.2"
  date: '2026-10-01'
  author: Amish Chadha
  change: Budget treated as a value-engineering target
- version: "0.3"
  date: '2026-10-02'
  author: Amish Chadha
  change: 'Amish approved the recommendations for all seven open decisions on 2026-10-02 (CVC-DDR-003 accepted); moved to decisions made'
---

# CulvertCrawl design decisions register

Every design decision still to be made, and every decision made, in one place. Each decision is argued in full in its decision record under `docs/decisions/`; this register is the index Amish works from. The build plan (`docs/05-build-plan.md`) describes the design as it stands and does not list open decisions.

## Open decisions

None. All open decisions were decided on 2026-10-02.

## To confirm when parts are bought

| # | What to confirm | Why it matters | Source |
| --- | --- | --- | --- |
| 1 | The worm gear motor's output shaft is 8 mm D and at least 38 mm long, its output face has two tapped holes, and the shaft sits about 8 mm above the gearbox base and 14 mm from its back | They set the drive pad, the seal counterbore and the side plate holes | CVC-DDR-003, P3 |
| 2 | The belt kit runs at 200 mm sprocket centres with 36 mm belts, and its sprocket can be bored 8 mm D with a set screw | There is no tensioner; the centres set the belt tension | CVC-DDR-003, P2, P11 |
| 3 | The dome's flange is 72 mm across and 5 mm thick | It sets the bezel recess and the O-ring groove | CVC-DDR-003, P6 |
| 4 | The camera board's hole pattern and the lens's position on its thread | They set the camera mount holes and put the lens centre at the dome centre | CVC-DDR-003, P5 |
| 5 | The laser module is 12 mm across and the cone mirror's base is 20 mm or less | They set the diode housing bore and fit inside the window | CVC-DDR-003, P8 |
| 6 | The slip ring has an anti-rotation tab or lead the anchor can catch, and passes 100 Mbit/s Ethernet | It sets the anchor bracket; the data link depends on it | CVC-DDR-003, P12 |
| 7 | The rugged case's inside size and moulded ribs | The chassis base board and panel must drop in with about 2 mm to spare | CVC-DDR-003, P14 |
| 8 | The battery's size laid on its side (181 x 167 x 77 mm in the model) and that its maker allows it on its side | It sets the battery bay | CVC-DDR-003, P14 |
| 9 | The tether's aramid member can be broken out and tied off at the eye bolt, and its outside diameter suits the M10 penetrator | Recovery pulls go through it | CVC-DDR-003, P10 |

## Value engineering

Value-engineering target: USD 910 (a hypothetical control target, not a limit). Estimated cost of the constructable design: USD 1,034 (USD 124 over the target). The estimate was USD 906 before the design for construction.

Main cost drivers (the parts added to make the design buildable): the reel frame, bearings, hubs and counter reader (USD 43), the front bezel and the side plates and small made parts (USD 32), the surface box chassis (USD 20), the eye bolt and screws (USD 10), the hull rim and pads (USD 8), the laser fin, window and cap (USD 8), the larger ballast plate (USD 4) and the deck (USD 3). Prices are indicative; the softest (hull, tether, cone mirror) can still move the total by USD 20 to USD 80 either way.

Savings worth trying: a bought cable reel, a printed bezel and a smaller case, then real quotes for the soft prices.

## Decisions made

| Date | Decision | Decided by | Record |
| --- | --- | --- | --- |
| 2026-09-25 | TRL 2 review items 1 to 8: budget $900, pipe range 300 to 900 mm, 12.8 V LiFePO4 surface battery, tracks, 48 V surface power, Class 2 laser ring and fisheye camera, processing on the laptop, pitch unchanged | Amish: "proceed with all of your recommendations across all batches. Make sure we don't proceed to TRL 4 on any of them." | CVC-DDR-001 |
| 2026-09-25 | Heavier ballast plate for reach (R2), with upstream entry in flooded pipes as operating guidance; ring plane moved to 300 mm ahead (R5); the $1 overrun accepted | Amish: "i accept all your recommendations, go with them across all repos." | CVC-DDR-002 |
| 2026-09-26 | Value-engineering target set to $910 to match the then priced BOM ($906) | Amish: "i approve all the budget items." | CVC-DDR-002 v0.2 |
| 2026-09-30 | Make the design physically buildable while drawing the build plan; changes recorded in CVC-DDR-003 (accepted on 2026-10-02, below) | Amish: "If you are realising that the design cannot be built as per concept - fix the design assumptions to match and be physically feasible as you draw the illustrations." | CVC-DDR-003 |
| 2026-09-30 | Outstanding decisions are kept in this register, not in the build plan | Amish: "don't log outstanding decisions in this build plan - that is not the place for it. that should be in a separate design document logged and named as such" | STANDARDS section 18 |
| 2026-10-02 | Design for construction accepted: all fourteen changes P1 to P14 and their knock-on changes, as made | Amish: "i approve your recommendations for all 555 open decisions." | CVC-DDR-003, Tables 1 and 2 |
| 2026-10-02 | Laser boom held by two M3 bolts at the fin bracket for the prototype; a tool-free clamp is to be decided after the first pipe trials | Amish: "i approve your recommendations for all 555 open decisions." | CVC-DDR-003, A2; CVC-DDR-001 item 11; CVC-DDR-002 item 6 |
| 2026-10-02 | The fin's shadow at the invert (6.4 % of the ring in 300 mm pipe) is accepted | Amish: "i approve your recommendations for all 555 open decisions." | CVC-DDR-003, A3 |
| 2026-10-02 | The 0.86 kg heavier crawler (6.63 kg) is accepted | Amish: "i approve your recommendations for all 555 open decisions." | CVC-DDR-003, A4 |
| 2026-10-02 | First output: the deflection report; second, observations logged in NASSCO PACP vocabulary; FHWA condition ratings later | Amish: "i approve your recommendations for all 555 open decisions." | CVC-DDR-001 item 9; CVC-DDR-002 item 4 |
| 2026-10-02 | First partner user group for field trials: a county road department, with a university transportation program as backup; first candidate to approach for the backup: the Texas A&M Transportation Institute | Amish: "i approve your recommendations for all 555 open decisions." | CVC-DDR-001 item 10; CVC-DDR-002 item 5 |
| 2026-10-02 | The lid status light stays in the renders only, and the control case position is render layout only; neither is added to the model | Amish: "i approve your recommendations for all 555 open decisions." | Review note, 2026-09-26, items 3 and 5 |

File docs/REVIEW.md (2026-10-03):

# Review note: CulvertCrawl

## Session 2026-09-25: /populate to a strong TRL 2

### What was done

- `docs/01-problem.md` (CVC-PRB-001 v0.2): problem, why entry and end views fail, users (road crews, public works, inspectors, watershed groups, owners, makers), operating environment, constraints, out of scope, prior work with sources, open questions and a co-design checklist.
- `docs/03-requirements.md` (CVC-REQ-001 v0.2): 13 measurable requirements (R1 to R13) with targets, verification and a first-order status for each, a defined design case, and a list of requirements not met or at risk.
- `docs/02-concept.md` (CVC-PRC-001 v0.2): how it works, numbered components, mass and buoyancy, traction and reach, power and endurance, laser ring profiling error budget, cost, design choices (all proposed), safety section, open questions and references.
- `cad/src/concept_media.py`: massing model of the crawler (hull, tracks, worm gear motors, electronics, fisheye camera and dome, LED ring, laser boom, ballast) plus tether, reel and surface box, each part with a BOM number; a sectioned 600 mm culvert and the projected laser ring are hero-only context.
- `media/`: `hero.png` (1.75 m scale figure), `concept-blueprint.png`, `.pdf` and `.svg`, `model.glb` and `viewer.html`, `exploded.png` with callouts 1 to 12, `cutaway.png` (crawler only), `flow.png` (power flow, estimates). Temporary `media/_views*` folders removed.
- `bom/bom.csv`: 13 lines, numbered to match the exploded view, with indicative USD prices; `bom/bom-notes.md` updated to match.
- `README.md`: hero image and links line inserted before "## Problem"; Problem, Concept and Key components updated to the concept.
- `docs/pdf/`: branded PDFs of the three controlled documents.
- `project.yaml`: unchanged. The pitch and problem still describe the concept correctly.

### Key results (estimates, to be checked at TRL 3)

| Quantity | Estimate | Requirement |
| --- | --- | --- |
| Crawler size and mass | 490 x 170 x 125 mm (including laser boom), about 5.5 kg | R1 met |
| Reach in the design case (600 mm, 5 % slope, wet silt, 20 % traction reserve) | about 56 m | R2 met, thin margin |
| Crawler power while driving and profiling | about 28 W; about 35 W from the battery | |
| Tether loss at 48 V over 60 m | about 1.3 W (4 %); about 3.4 V drop at 50 W peak | |
| Endurance on a 12.8 V 20 Ah LiFePO4 battery | about 6 h | R9 met |
| Profile accuracy, 300 / 600 / 900 mm pipe | about 0.2 % / 0.5 % / 0.8 to 1.2 % of diameter | R5 met to 600 mm, at risk at 900 mm |
| Profile spacing at 0.15 m/s | about 12 mm | R5 met |
| Net weight fully submerged | about 3.0 kg (traction about half of dry) | R7 partly |
| Whole kit mass | about 18 kg | R10 met on mass |
| Parts cost | about $900 (crawler about $421; tether, reel and surface kit about $450; consumables $30) | **R12 not met, about 13 % over** |

Requirements not met or at risk:

- **R12 (cost) not met:** about $900 against $800.
- **R5 at risk at 900 mm:** the top of a 900 mm pipe sits about 76 degrees off the camera axis, near the edge of the fisheye, where 1 % is marginal.
- **R7 unverified:** IP68 to 1 m with rotating shaft seals is the most likely failure; profiling works only above the water line.
- **R2 margin thin:** tether drag in bends, on corrugations or with a muddy jacket could cut reach below 50 m.
- **R4 lighting at 900 mm, R8 step crossing and R10 setup time** are unverified.

### Proposed, awaiting Amish

Status update: items 1 to 7 were decided by Amish, 2026-09-25: go with recommendation (CVC-DDR-001). Items 8 and 9 had no recommendation and stay Proposed, awaiting Amish.

1. **Budget.** Options: (a) raise `budget_usd` from $800 to $900; (b) cut to $800 by shortening the tether to 30 m and dropping the slip ring (surface box rides on the reel and talks to the laptop over Wi-Fi), which reduces reach to about 25 m and adds a radio link; (c) keep $800 and treat the surface kit as shared equipment costed separately. Recommendation: (a), because reach and a wired link are central to the pitch. `project.yaml` is unchanged.
2. **Pipe range.** Keep 300 to 900 mm (R5 at risk at 900 mm) or narrow to 300 to 600 mm (R5 met throughout). Recommendation: keep 300 to 900 mm and test the 900 mm case early at TRL 3.
3. **Surface battery.** A 12.8 V LiFePO4 battery with a 48 V boost (about $90) or the portfolio's SwapCell pack (48 V class, about $370, needs a CAN host heartbeat). Recommendation: LiFePO4 for the prototype, SwapCell-compatible input as a later option.
4. Tracks rather than wheels.
5. Surface power over the tether at 48 V DC rather than a battery in the crawler.
6. Class 2, 520 nm laser ring 200 mm ahead of a fixed fisheye camera, rather than a structured-light or stereo camera or a pan-tilt head.
7. Processing and reporting on the operator's laptop rather than in the crawler.
8. Output format first: PACP-style observation log, FHWA condition ratings or a deflection report.
9. First partner user group for field trials (county road department, watershed group or university transportation program).

### Safety concerns

- Confined space: the tool exists to avoid entry; recovery must never involve entering the pipe (OSHA 29 CFR 1910.146).
- Flammable atmospheres: the crawler is not intrinsically safe; sewers and gas-bearing drains are out of scope, and air should be checked at the mouth of any enclosed drain.
- Roadside traffic, steep wet banks and fast or rising water at culvert mouths.
- LiFePO4 battery of about 256 Wh in the surface box: BMS, fuse, matched charger, no charging when damaged or wet.
- 48 V DC on a long tether in water: fuse, overcurrent cutoff, latching emergency stop, jacket inspection.
- Class 2 laser: do not stare into the beam; switch off when out of the pipe.
- Track pinch points, reel crank kickback, tether trips, sharp rusted edges and wildlife.

### Problems and notes

- The web search budget for this batch was exhausted before this repo, and direct web fetches were blocked, so no new searches were possible. Sources are cited from well-known documents (OSHA, FHWA culvert manuals, ASTM D2321, NASSCO PACP, Duran and coauthors in IEEE journals, IEC 60825-1 and 60529) and are marked in the documents as not rechecked online. Commercial price ranges are labeled as estimates. Check every citation and link at TRL 3.
- The 5 % deflection limit is described as common practice following AASHTO and state DOT specifications; the exact clause should be confirmed.
- In the exploded view, the surface kit (items 9 to 12) is drawn displaced in front of the crawler so the crawler parts stay legible; the crawler parts are small relative to the reel and case.
- The hero view is at human scale, so the crawler is small in the image; the cutaway and exploded views show it in detail.
- The legacy `cad/src/model.py` placeholder is untouched (TRL 3 work).

### Recommended next step

Review this note and the media, then decide items 1 to 3. If approved, run `/advance-trl3` to check the traction and reach, tether power, buoyancy and laser profiling error budget by calculation, and to produce the parametric model and drawing sheet.

## Session 2026-09-25: TRL 3

Amish approved all TRL 2 recommendations on 2026-09-25 ("proceed with all of your recommendations across all batches. Make sure we don't proceed to TRL 4 on any of them."). This session ran `/advance-trl3` and stopped at TRL 3.

### What was done

- `docs/decisions/0001-trl2-review-decisions.md` (CVC-DDR-001 v0.1): eight decided items and three that stay open.
- `docs/04-calcs/01-sizing.md` (CVC-CAL-001 v0.1) with `docs/04-calcs/sizing.py` and `results.csv`: fit, mass and buoyancy, traction and reach (dry and submerged, both directions), recovery pull, tether power and endurance, a Monte Carlo profiling error budget, laser signal, video link, lighting, hull thermal and cost. The script reads `cad/src/model.py` and `bom/bom.csv`.
- `cad/src/model.py`: parametric build123d model (crawler and surface kit) exporting `cad/step/culvertcrawl-crawler.step`, `cad/step/culvertcrawl-surface-kit.step` and matching STL files.
- `cad/src/sheets.py` and `cad/drawings/CVC-DWG-001.svg`, `.pdf`, `.png`: general arrangement, Rev P1, with end-view fit checks in 300 and 900 mm pipe. The concept blueprint keeps CVC-DWG-010.
- `bom/bom.csv` and `bom/bom-notes.md`: every line priced with a supplier type; specification changes for the camera (50 fps, circular fisheye) and fuses (10 A battery, 2 A tether). Total $901.
- `cad/src/concept_media.py` now builds from the model; all media in `media/` regenerated and checked; `media/_views*` removed.
- CVC-PRB-001, CVC-PRC-001 and CVC-REQ-001 moved to v0.3; `project.yaml` (`trl: 3`, `trl_target: 3`, `budget_usd: 900`, evidence list); `README.md` updated. Pitch and problem wording unchanged, as recommended.

### Requirements (CVC-CAL-001)

3 not met, 2 at risk, 1 not verifiable at TRL 3, 7 met on paper.

| ID | Status | Key number |
| --- | --- | --- |
| R2 Reach | **Not met** | 39 m submerged, uphill against 0.5 m/s flow (target 50 m); 52 m dry uphill; 85 to 158 m downhill. Falls to about 3 m if submerged track friction is 0.45 |
| R5 Profile | **Not met at 900 mm** | Vertical diameter error 1.59 % at 900 mm; 0.87 % at 600 mm; 0.35 % at 300 mm; 6 mm spacing |
| R12 Cost | **Not met** | $901 against $900 |
| R7 Water | At risk | Holds in flow on paper; fully submerged in the design case; IP68 not verifiable |
| R8 Climb | At risk | Hold met; 40 mm step against a 35 to 53 mm limit |
| R6 Locate | Not verifiable at TRL 3 | Encoder resolution 0.26 mm; slack and slip unknown |
| R1, R3, R4, R9, R10, R11, R13 | Met on paper | 170 x 106 x 510 mm; 50 N pull, factor 20; 25 fps, 53 % link; 6.4 h; 17.6 kg; 48 V with 2 A and 10 A fuses |

Corrections to TRL 2 numbers: crawler 5.3 kg (was 5.5 kg) and 106 mm high (was 125 mm); tether current 0.67 A and loss 1.40 W (was 0.65 A, 1.3 W); battery draw 36.0 W and 6.4 h (was 35 W, about 6 h); reach now includes lifting the tether up the grade and full submersion; lens needs a 180 degree circular fisheye at 0.139 degree per pixel (was 0.1 degree per pixel, not achievable while seeing the pipe top); profile spacing 6 mm at 50 fps (was 12 mm, which left video at 12.5 fps and missed R4); the 5 A fuse was below the 5.4 A peak battery current.

### Decisions recorded (CVC-DDR-001)

Decided by Amish, 2026-09-25, go with recommendation: budget $900; pipe range 300 to 900 mm; LiFePO4 surface battery (SwapCell input later, citing interface v0.3); tracks; 48 V surface power; Class 2 520 nm laser ring with fixed fisheye; processing on the laptop; pitch and problem unchanged.

### Still awaiting Amish

1. Output format first (PACP-style log, FHWA ratings or deflection report); no recommendation was made.
2. First partner user group; not named (partners are picked per area later).
3. Removable laser boom; no recommendation was made.
4. **New, R2:** Decided by Amish, 2026-09-25: go with recommendation (CVC-DDR-002; applied in the session below). Options were (a) add about 0.40 kg of ballast (restores 50 m wet uphill on paper at friction 0.6, but not at 0.45); (b) redefine the design case as entering from the upstream end; (c) accept a shorter reach in flooded pipes. Recommendation: (a) plus (b) as operating guidance; submerged track friction needs measuring once Amish lifts the TRL 4 hold.
5. **New, R5:** Decided by Amish, 2026-09-25: go with recommendation (CVC-DDR-002; applied in the session below). Options were (a) move the ring plane to 300 mm ahead (0.97 % at 900 mm, 100 mm longer boom); (b) narrow acceptance-grade profiling to 300 to 600 mm and report 900 mm as screening; (c) tilt the camera up. Recommendation: (a).
6. **New, R12:** Decided by Amish, 2026-09-25: go with recommendation (CVC-DDR-002). Options were: accept $901 as within pricing uncertainty, or trim $1 or more. Recommendation: accept and revisit when real quotes exist.

### Safety concerns

Unchanged from TRL 2, plus: the design-case crawler is fully submerged, so seal integrity on the drive shafts and lid is the main failure mode; never tie the tether to a vehicle (the 1 kN member and cable whip); the fuse split must be kept (10 A battery, 2 A tether, 1.5 A cutoff); the hull runs about 15 K above ambient in air, so the Pi needs a heat path to the wall. Confined space, flammable atmosphere, roadside traffic, fast water, LiFePO4 and Class 2 laser notes stay in CVC-PRC-001.

### Citations

Checked online on 2026-09-25: OSHA 29 CFR 1910.146 (title and definition), FHWA-IP-86-2 (1986), FHWA-CFL/TD-10-005 (2010), and both Duran, Althoefer and Seneviratne papers by title and journal (the 2007 paper at *IEEE Transactions on Automation Science and Engineering* 4, page 118). Still unchecked: the ASTM D2321 5 % deflection clause, NASSCO PACP, IEC 60825-1, IEC 60529 and commercial product pages.

### Existing TRL 4 material

None found. `build-log/` holds only its README and `.gitkeep`; `firmware/` and `electronics/` are empty.

### Recommended next step

TRL 4 is on hold by Amish's instruction. Next, Amish decides items 1 to 6 above; if 4 or 5 are accepted, a TRL 3 revision updates the model, the CAL note and the drawing to Rev P2. For the record only, TRL 4 would need: a submerged track friction and drawbar test on silt, a tank test of the sealed hull and shaft seals to 1 m, a laser ring calibration in 300, 600 and 900 mm reference pipes, a Pi 4 frame-rate and encoder load test, a test report (TST, `environment: lab`) and build log entries.

## Session 2026-09-25: recommendations accepted

On 2026-09-25 Amish wrote: "i accept all your recommendations, go with them across all repos." This session applied that instruction at TRL 3 and recorded it in CVC-DDR-002 (`docs/decisions/0002-recommendations-accepted.md`). TRL 4 remains on hold.

### Decisions applied and what changed

| Item | Decision | Before | After |
| --- | --- | --- | --- |
| R2 reach | Decided by Amish, 2026-09-25: go with recommendation. Add ballast; upstream entry in flooded pipes as operating guidance | Ballast 210 x 80 x 12 mm, 1.67 kg; crawler 5.31 kg, 2.66 kg net submerged; wet uphill reach 39 m | Ballast 230 x 80 x 14 mm, 2.13 kg, 8 mm above the contact line; crawler 5.77 kg, 3.05 kg net; wet uphill reach 52 m (about 10 m at friction 0.45) |
| R5 at 900 mm | Decided by Amish, 2026-09-25: go with recommendation. Ring plane 300 mm ahead | Ring 200 mm ahead; crawler 510 mm long; 1.59 % at 900 mm | Ring 300 mm ahead; crawler 610 mm long; 0.97 % at 900 mm (0.62 % at 600 mm, 0.24 % at 300 mm) |
| R12 cost | Decided by Amish, 2026-09-25: go with recommendation. Accept $1 over as pricing uncertainty; revisit with real quotes | $901 | $906 after the two changes above (ballast +$3, boom +$2); `budget_usd` stays 900 |

Files changed: `cad/src/model.py` (and STEP and STL re-exported), `cad/src/sheets.py` and CVC-DWG-001 Rev P1 to Rev P2, `cad/src/concept_media.py` and all of `media/`, `docs/04-calcs/sizing.py`, `results.csv` and CVC-CAL-001 v0.1 to v0.2 (Monte Carlo now 2,000 trials), `bom/bom.csv` and `bom/bom-notes.md`, CVC-PRB-001, CVC-PRC-001 and CVC-REQ-001 v0.3 to v0.4, CVC-DDR-001 v0.1 to v0.2, new CVC-DDR-002, `README.md` (numbers and the four write-up sections), `project.yaml` (DDR-002 added to the evidence list only), and `docs/pdf/`. Other knock-on numbers: kit 17.6 to 18.1 kg; sprocket torque 0.67 to 0.73 N·m; recovery pull 50 to 53 N (factor 18.9).

The README gained "Concept rationale", "Burning platform", "Where it could be used" and "What sparked the idea". The inspiration point is Florida DOT Standard Specifications Section 430 (Rev 12-7-07), which requires laser-profile video inspection of new pipe of 48 in or less but lets short cross drains be inspected from each end.

### Requirement status (CVC-CAL-001 v0.2)

| ID | Status | Key number |
| --- | --- | --- |
| R12 Cost | **Not met** | $906 against $900; $1 accepted by Amish, $5 awaiting Amish |
| R7 Water | At risk | IP68 not verifiable at TRL 3; holds in the flow (2.5 N drag against 18.7 N) |
| R8 Climb | At risk | Hold met; 40 mm step against a 35 to 53 mm limit |
| R6 Locate | Not verifiable at TRL 3 | Slack and slip unknown |
| R2 Reach | Met on paper, thin margin | 52 m wet uphill; about 10 m if submerged track friction is 0.45 |
| R5 Profile | Met on paper, thin margin at 900 mm | 0.24 / 0.62 / 0.97 % at 300 / 600 / 900 mm |
| R1, R3, R4, R9, R10, R11, R13 | Met on paper | 170 x 106 x 610 mm; 53 N pull, factor 18.9; 25 fps; 6.4 h; 18.1 kg; 48 V fused |

### Still awaiting Amish

1. Output format first (PACP-style log, FHWA ratings or deflection report); no recommendation was made.
2. First partner user group; not named.
3. Removable laser boom; no recommendation was made. It matters more now that the boom overhangs the tracks by about 300 mm.
4. **New:** the $5 added by the ballast and boom changes ($906 against $900). Recommendation: accept on the same basis as the first $1 and revisit with real quotes. Decided by Amish, 2026-09-26: budget set to $910 (CVC-DDR-002 v0.2).

### Cross-repo actions

None. No decision in this repo needs another repo to change.

### Safety

Unchanged. The heavier crawler raises the locked-track recovery pull to 53 N, still a factor of 18.9 on the 1 kN tether member; never tie the tether to a vehicle. The longer boom puts the laser 300 mm ahead of the tracks, so keep the Class 2 rule of switching the laser off out of the pipe.

### TRL 4

TRL 4 remains on hold by Amish's instruction. Decided but on hold: measuring submerged track friction and drawbar pull on silt, calibrating the ring in 300, 600 and 900 mm reference pipes, and getting real supplier quotes. `trl: 3` and `trl_target: 3` are unchanged.

## Session 2026-09-26: sources strengthened

Amish asked for the weaker sources in the README to be fixed. Every link kept or added was fetched and checked against the claim (World Bank flood assessment, FHWA culvert program, WSDOT injunction page, FDOT Section 430, GFDRR Cambodia). No controlled document changed; `docs/01-problem.md` did not share any of the replaced claims.

| Where | Old source | New source |
| --- | --- | --- |
| United Kingdom and northern Europe row | Uncited | Row narrowed to the United Kingdom: over one million culverts and outfalls with blockage and sedimentation risk (CIRIA and Environment Agency *Culvert, screen and outfall manual*, GOV.UK page), plus Devon County Council culvert guidance |
| India row | Uncited | Press Information Bureau (Government of India) PMGSY factsheet: about 783,700 km completed by August 2025; maintenance payments tied to the condition of cross-drainage works |
| East Africa row | World Bank 2022 flood assessment, plus an uncited claim about silted culverts on unpaved roads | Row renamed Mali and Sudan, the countries the same World Bank source names, and limited to what it states |
| Burning platform, culvert sentence | Uncited claim that many failures start at culverts | Softened to a statement that culverts are among the buried links in those networks |

The inspiration event (FDOT Standard Specifications Section 430) is unchanged; its link was rechecked against the quoted clause. No budget change.

## Session 2026-09-26: budget approved

On 2026-09-26 Amish wrote: "i approve all the budget items." The open budget item (the $5 from the ballast and boom changes) is decided: budget set to $910 to cover the priced BOM, recorded in CVC-DDR-002 v0.2.

- `project.yaml`: `budget_usd` 900 to 910. The priced BOM is $906, so the figure covers it with $4 to spare.
- R12: **not met** ($6 over $900) to **met**. Requirement status is now 0 not met, 2 at risk (R7, R8), 1 not verifiable (R6) and 10 met on paper.
- `docs/04-calcs/sizing.py` reads the budget from `project.yaml` and was rerun (`results.csv` updated); CVC-CAL-001 v0.3, CVC-REQ-001 v0.5, CVC-PRC-001 v0.5, CVC-PRB-001 v0.5, `README.md` and `bom/bom-notes.md` quote the new figure. The concept blueprint key figure now reads "against the $910 budget", and `media/` was regenerated.
- Still awaiting Amish: output format, first partner user group, removable laser boom.

## Session 2026-09-26: product appearance model and photoreal renders

Amish chose this repo for the first batch of product renders on 2026-09-26. This session adds an appearance model for photoreal renders; no controlled document, the BOM or `cad/src/model.py` changed.

### What was added

- `cad/src/product_model.py`: `product_parts()`, `TITLE` and `RENDER_VIEWS` (hero, exploded and a crawler-only detail view). It imports `PARAMS` and `track_contact_height()` from `model.py` and rebuilds each part from the same parameters and placements as `crawler_parts()` and `surface_parts()`, so every main dimension and interface is kept. Appearance detail added:
  - Crawler hull: clear-anodized body with filleted edges and machined side flutes, teal anodized lid on its lip with a recessed name plate and accent bar, four stainless lid screws, a hex pressure-test plug, a lit status light, a dome clamp flange and a hex tether gland.
  - Tracks: lugged rubber belts over toothed sprockets and dished idlers with hub caps; slotted inner side plates.
  - Front end: fisheye camera module and lens behind a clear acrylic dome shell (bore cut through the front wall so the camera shows), black LED bezel with eight lit emitters.
  - Laser projector: clear boom with its cable visible inside, clamp collar at the dome, knurled diode housing, clear exit window around the cone mirror and an end cap.
  - Internals split for colour: worm gear motor cans, gearboxes and shafts; carrier board, Pi 4 layer with ports and heatsink, and the converter block.
  - Ballast skid plate with filleted edges, flush countersunk bolts and skid grooves; ribbed tether bend restrictor.
  - Surface kit: reel with lightened flanges, wound tether, teal A-frame with feet, crank and knob, slip ring and lead, payout counter with wheel and lit readout; rugged control case with parting groove, ribs, latches, handle, emergency stop, connectors, fuse holders and a lit tether power light; gamepad with sticks and buttons.
  - Context (hero only): a short cut-open section of 600 mm corrugated steel culvert, the laser ring lit on its wall (illustrative), a ground patch and the shared 1.75 m clay mannequin standing at the reel.
- `README.md`: hero image now points to `media/render-hero.png`, with an exploded render link. The render files are produced separately.

### Where the appearance model differs from model.py

Each item is **Proposed, awaiting Amish**.

1. **Laser head exit window and end cap.** `model.py` shows the cone mirror bare beyond a 26 mm diode housing. The appearance model splits the head into a 14 mm housing, a clear window around the mirror and a 3 mm end cap, so the head ends about 3 mm further forward (x 429 instead of 426 in the crawler frame). The ring plane stays 300 mm ahead of the dome center. Recommendation: adopt the window and cap in `model.py` at the next model revision; a bare mirror would foul in a pipe.
2. **Dome bore and dome shell.** `model.py` has no bore in the front wall and a solid dome. The appearance model cuts a bore of dome radius less 1 mm and makes the dome a 3 mm shell. Recommendation: adopt; it matches the BOM (60 mm dome bore, acrylic dome port).
3. **Status light on the lid.** Not in the BOM or `model.py`. Recommendation: keep for the render only unless Amish wants a power indicator; if kept, it is a small sealed panel LED under item 13.
4. **Payout counter bracket.** `model.py` leaves the payout counter unsupported beside the reel; the appearance model adds two small tubes from the frame. Recommendation: adopt in `model.py`.
5. **Control case position (render layout only).** Moved from beside the reel to the front left of the scene so the hero stays compact; no size changed. Recommendation: keep as a render layout.
6. **Track belt build-up.** The belt outer surface is 3 mm inside the `model.py` track radius and the lugs make up the 35 mm radius, so the contact line and track height are unchanged. No action needed.

### Status

This is an appearance model only: no tolerances, no fabrication detail and nothing beyond TRL 3. `trl: 3` and `trl_target: 3` are unchanged, and TRL 4 remains on hold.

## Session 2026-09-27: kit 1.5.0 and image quality

- Kit 1.5.0 synced: STANDARDS v1.5 (sections 12 to 15: product renders, storefront images and image quality, public release, authorship and signing), `.kit/cards.py`, `.kit/image_qc.py`, `.kit/release_gate.py`, issue templates, and the `/render-product` and `/release` commands. `CLAUDE.md` now matches `.kit/CLAUDE.md`.
- Every `media/render-*.png` recaptioned from its original render with the new layout: the title, concept label and repository sit in a band above the render and the view note in a band below it, each line wrapped to the image width, so no text overlaps other text or the render or runs off the image. `media/card.png` and `media/social-preview.png` regenerated with the same rules.
- `python .kit/image_qc.py` and `python .kit/release_gate.py` pass. trl stays 3.

## Session 2026-09-30: kit 1.7.0, design for construction and prototype build plan

Amish approved the build plan format on 2026-09-30 and asked for it in every repo, with outstanding decisions kept in a separate design decisions register. He also wrote: "If you are realising that the design cannot be built as per concept - fix the design assumptions to match and be physically feasible as you draw the illustrations."

### What was done

- Kit 1.7.0 installed (`.kit/`, `.claude/commands/`); `CLAUDE.md` replaced with `.kit/CLAUDE.md`.
- `cad/src/model.py`: rewritten as a constructable model with every component and fixing, and 94 constructability checks (`python cad/src/model.py --check`); all pass. STEP and STL regenerated (`cad/step/`, `cad/stl/`).
- `docs/decisions/0003-design-for-construction.md` (CVC-DDR-003 v0.1, Draft): every change, made under Amish's 2026-09-30 instruction to make the design physically buildable; open for his review.
- `bom/bom.csv`: 15 lines (new line 14, front bezel; new line 15, side plates and small made parts; lines 1 to 11 and 13 respecified); `bom/bom-notes.md` updated.
- `docs/04-calcs/sizing.py` and CVC-CAL-001 v0.4: masses from model volumes, fin shadow in the profiling Monte Carlo, reel and box masses from the model; `results.csv` rerun. CVC-REQ-001 v0.6, CVC-PRC-001 v0.6 and CVC-PRB-001 (budget line) updated to match.
- `cad/drawings/CVC-DWG-001` Rev P3 (`cad/src/sheets.py`); concept media regenerated (`cad/src/concept_media.py`, blueprint CVC-DWG-010 Rev P2, `media/model.glb` and `viewer.html`).
- `cad/src/build_plan_media.py` (uses `.kit/build_views.py`): two overview pictures, 19 making sketches (`cad/drawings/CVC-DWG-101` to `119`), 15 joint close-ups, 23 step pictures, a hull hole layout and a wiring diagram, all in `docs/05-build-plan/`.
- `docs/05-build-plan.md` (CVC-BLD-001 v0.1) and `docs/06-design-decisions.md` (CVC-DEC-001 v0.1).
- `project.yaml`: `design_state: constructable`; DDR-003, the build plan and the register added to `trl_evidence`. `README.md`: links line and a "Building the prototype" section (the README has no Safety section, so it sits after Key components).

### Design changes made for construction (CVC-DDR-003)

1. Hull machined from a block with a 12 mm inner rim carrying the lid O-ring and ten M4 screws; flush lid (the 3 mm lip is gone); 10 mm front wall; drive pads, idler bosses and floor pads inside.
2. Track belts 36 mm (were 40 mm) with the same outer edge, so a 3 mm side plate fits between hull and belt; width 170 mm unchanged.
3. Made side plates on both sides, held by the gearbox screws, the idler axle and three screws into the ballast plate; they tie the hull to the ballast plate.
4. Gearboxes moved 2 mm inside the rear wall, output faces on the drive pads with two screws each; lip seals in counterbores in the side walls, kept in by the side plates.
5. Idler axles: M6 shoulder bolts into blind tapped bosses in the hull walls.
6. Electronics tray on four floor pads; Pi on spacers; a deck on standoffs carries the driver, converters and IMU (the converter no longer sits inside the motor cans).
7. Camera bore in the front wall and a printed camera mount.
8. Machined front bezel (BOM line 14) clamps the dome flange on an O-ring and holds eight stock LEDs, potted; LED and laser leads through a potted hole in the front wall.
9. Laser boom carried on an 8 mm clear acrylic fin bolted to a bracket on the ballast plate's nose (it no longer touches the dome).
10. Laser head with a clear window tube and end cap holding the cone mirror (the appearance model's 2026-09-26 proposal, item 1); ring plane still 300 mm ahead.
11. Ballast plate 255 x 88 x 14 mm (was 230 x 80 x 14 mm with a bent lip), square nose, tapped for the side plates, fin bracket and eye bolt; 2.45 kg.
12. Tether strength member tied to an M8 eye bolt in the ballast plate; M10 penetrator raised to 77 mm (was on the camera axis) to clear the gearboxes.
13. Reel: two 6 mm aluminium side frames on spacer tubes, flanged bearings, hollow axle, PVC drum clamped between HDPE flanges by tie rods, shaft hubs, crank, knob brake, slip ring anchor bracket.
14. Payout counter on a bar clamped in the front spacer (review item 4 of 2026-09-26), with a USB encoder reader.
15. Surface box drop-in chassis (base board, four posts, panel); battery on its side, strapped; the case is not drilled.

### Key results (CVC-CAL-001 v0.4)

- Crawler 6.63 kg (was 5.77 kg), 3.77 kg net submerged; kit 22.2 kg, heaviest item 7.8 kg. R10 met.
- Wet uphill reach 75 m (was 52 m); 23 m if submerged track friction is 0.45. Sprocket torque 0.84 N·m against the 1 N·m rating. Recovery pull 59 N, factor 17.
- Profiling with the fin's shadow: 0.25, 0.57 and 0.97 % of diameter at 300, 600 and 900 mm. R5 met, thin margin at 900 mm.
- **R12 over the value-engineering target:** BOM $1,034 against a $910 target ($124 over). `budget_usd` unchanged.
- Status: 1 over its value-engineering target (R12), 2 at risk (R7, R8), 1 not verifiable (R6), 9 met on paper.

### Proposed, awaiting Amish

All open items are in the design decisions register (`docs/06-design-decisions.md`): accepting CVC-DDR-003; the removable boom (two bolts for the prototype); the fin shadow; the heavier crawler; and the items still open from earlier (output format, first partner, appearance-model differences).

### Stale media

The design changed visibly, so these are out of date and are made on Amish's Mac, not here: `media/render-hero.png`, `media/render-exploded.png`, `media/render-detail.png`, `media/card.png`, `media/social-preview.png`, and the appearance model `cad/src/product_model.py` (concept lid lip, 88 mm LED ring, bare cone, tube reel frame). The render files referenced by the README are not present in this copy.

### Safety

No change to the safety case. The recovery pull now goes to an eye bolt in the steel plate instead of the cable seal. The build plan adds safety stops for the battery, the 48 V tether, the laser and the leak test.

### Recommended next step

Amish reviews CVC-DDR-003 and the register (including its Value engineering section). TRL 4 remains on hold; `trl` and `trl_target` stay at 3.

## Session 2026-10-02: open-decision recommendations approved

Amish, 2026-10-02: "i approve your recommendations for all 555 open decisions." This approves the recommendation for every open decision in the design decisions register. 7 decisions were recorded: each moved to Decisions made, dated 2026-10-02, with the approved recommendation and its record. trl stays 3; no build or test work was done, and the CAD model, BOM quantities and prices, and pictures were not changed.

### Documents changed

- `docs/06-design-decisions.md` (CVC-DEC-001 v0.3): the seven open decisions moved to Decisions made; Open decisions now reads none
- `docs/decisions/0003-design-for-construction.md` (CVC-DDR-003 v0.3): status accepted with Amish's words (Tables 1 and 2, A2 to A4); Table 3 marked accepted as recommended; consequence added
- `docs/decisions/0001-trl2-review-decisions.md` (CVC-DDR-001 v0.3): items 9 to 11 (output order, first partner, removable boom) decided
- `docs/decisions/0002-recommendations-accepted.md` (CVC-DDR-002 v0.3): items 4 to 6 decided
- `docs/02-concept.md` (CVC-PRC-001 v0.8): removable boom and output order stated as decided; design for construction accepted; answered open questions removed or updated
- `docs/01-problem.md` (CVC-PRB-001 v0.8): open questions on the first partner and the output order answered
- `README.md`: concept paragraph: deflection report first, PACP vocabulary second, FHWA ratings later
- PDFs regenerated with `python3 .kit/render.py`; superseded PDF versions removed by the render.

### Follow-up actions to carry approved decisions into the design

1. Decision 1 (pictures): Regenerate the photoreal renders, `media/card.png` and `media/social-preview.png` from `cad/src/product_model.py` so they show the accepted construction (hull rim and flush lid, bezel with LEDs, laser fin and window, reel frame), on Amish's Mac
2. Decision 5 (docs): Specify the laptop software's outputs in that order: the deflection report first (R5), then the observation log in NASSCO PACP vocabulary (R13), with FHWA condition ratings later

### Points found in the review

- The value-engineering target ($910) was set to match the BOM before construction ($906); the $124 overrun is entirely parts added to make it buildable, so a target reset may be fairer than the savings list suggests.

## Approved follow-ups carried out (2026-10-02)

Amish approved all follow-up actions from the 2026-10-02 sign-off. No decision changed the geometry, BOM or calculations of this repo, so the model, BOM, calculation note and drawings are unchanged (cost USD 1,034 against the USD 910 target, mass 6.63 kg, as before).

### Follow-ups

1. Decision 1 (renders): done in part. The appearance model (`cad/src/product_model.py`) already follows the accepted construction with every main dimension taken from `cad/src/model.py`; the render scenes were exported to `/home/claude/renders/culvertcrawl` (hero, exploded, detail, plus the jobs file). Not done: the photoreal renders, `media/card.png` and `media/social-preview.png`, which are made on Amish's Mac.
2. Decision 5 (docs): done. `docs/03-requirements.md` (CVC-REQ-001 v0.8) now states the laptop software's outputs in order: the deflection report first (R5), the observation log in NASSCO PACP vocabulary second (R13), FHWA condition ratings later.

### Cross-repo actions

None.

## 2026-10-02: photoreal renders redone on the constructable design

Rendered with Blender Cycles on Amish's Mac from the updated appearance model; captioned with `.kit/photo_caption.py`; `media/card.png` and `media/social-preview.png` regenerated with `.kit/cards.py`. Views: hero, exploded, detail. image_qc passes. Appearance deviations are those logged above as proposed, awaiting Amish.

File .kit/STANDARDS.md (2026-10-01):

---
doc_id: OHP-STD-001
title: Documentation and drawing standard
project: Open Hardware Portfolio
doc_type: Standard
version: "1.7"
status: Released
date: 2026-09-30
author: Amish Chadha
license: CC-BY-SA-4.0
revisions:
  - version: "1.0"
    date: 2026-09-24
    author: Amish Chadha
    change: First release of the standard
  - version: "1.1"
    date: 2026-09-24
    author: Amish Chadha
    change: Adopt Technology Readiness Levels (section 9) for project maturity
  - version: "1.2"
    date: 2026-09-24
    author: Amish Chadha
    change: Portfolio phase cap (section 10), concept media standard (section 11), CLAUDE.md guardrails
  - version: "1.3"
    date: 2026-09-24
    author: Amish Chadha
    change: Scale figure, interactive 3D viewer and flow diagrams added to concept media; session slash commands
  - version: "1.4"
    date: 2026-09-26
    author: Amish Chadha
    change: Every sheet and render names the project and its GitHub repository; overall dimensions, ISO centre lines and 300 dpi PNG on sheets; titles name the device and view labels state the viewing direction; optional photoreal renders with Blender
  - version: "1.5"
    date: 2026-09-27
    author: Amish Chadha
    change: Product renders (section 12), storefront images and image quality check (section 13), public release and release gate (section 14), authorship, citation and commit signing (section 15)
  - version: "1.6"
    date: 2026-09-29
    author: Amish Chadha
    change: Licensing metadata with REUSE (section 16), Zenodo DOI and Software Heritage archiving (section 17), release gate checks REUSE and a single CITATION.cff license, archive.py
  - version: "1.7"
    date: 2026-09-30
    author: Amish Chadha
    change: Concept and constructable design states; design decisions register (DEC) kept apart from the build plan; prototype build plan (BLD, section 18) with pictures by component is required TRL 3 evidence; every repo targets TRL 3 during the populate phase; build_views.py; /to-trl3 and /build-plan commands
---

# Documentation and drawing standard

Every project in the portfolio uses this standard, so that each precis, write-up and sketch looks the same and carries its own version history. The standard ships as a kit in each repo's `.kit/` folder. The kit version is in `.kit/KIT_VERSION`.

## 1. Document types and IDs

Every controlled document has a unique ID in the form `PRJ-TYP-NNN`.

- `PRJ` is the three-letter project code listed in section 7.
- `TYP` is the document type code from the table below.
- `NNN` is a sequence number within that project and type, starting at 001.

| Code | Type | Typical file |
| --- | --- | --- |
| PRC | Design precis | `docs/02-concept.md` |
| PRB | Problem statement | `docs/01-problem.md` |
| REQ | Requirements | `docs/03-requirements.md` |
| CAL | Calculation or sizing note | `docs/04-calcs/*.md` |
| DDR | Design decision record | `docs/decisions/*.md` |
| BOM | Bill of materials | `bom/bom.csv` |
| DWG | Drawing or sketch sheet | `cad/drawings/*.svg` |
| BLD | Prototype build plan (section 18) | `docs/05-build-plan.md` |
| DEC | Design decisions register (section 18) | `docs/06-design-decisions.md` |
| TST | Test plan or test report (front matter adds `environment: lab` or `relevant`) | `docs/05-tests/*.md` |

Example: `TBK-PRC-001` is the ThermaBrick design precis.

## 2. Revision scheme

| Artifact | While in draft | When released | Change after release |
| --- | --- | --- | --- |
| Documents | 0.1, 0.2, 0.3 ... | 1.0 | 1.1 for minor edits, 2.0 for a design change |
| Drawings | Rev P1, P2 ... (preliminary) | Rev A | Rev B, C ... |

- Every change to a controlled document adds a row to its revision history before the commit.
- The `version` field in front matter always equals the newest row in `revisions`. The renderer rejects a document where they differ.
- Status is one of `Draft`, `In review`, `Released` or `Superseded`. Draft and In review documents print with a status band on every page.
- Every release is tagged in Git as `<doc_id>/v<version>`, for example `TBK-PRC-001/v1.0`. Drawings are tagged `TBK-DWG-001/revA`.
- Git history is the full audit trail. The in-document revision table is the human-readable summary.

## 3. Document front matter

Every Markdown document under version control starts with this block:

```yaml
---
doc_id: TBK-PRC-001
title: ThermaBrick design precis
project: ThermaBrick
doc_type: Precis
version: "0.1"
status: Draft
date: 2026-09-24
author: Amish Chadha
license: CERN-OHL-S-2.0
revisions:
  - version: "0.1"
    date: 2026-09-24
    author: Amish Chadha
    change: Initial draft
---
```

Quote version numbers so YAML keeps `1.0` as text instead of turning it into a number. List revisions newest last.

## 4. Writing style

- Chicago Manual of Style.
- No em dashes. Restructure the sentence instead.
- Lead each section with its conclusion, then support it.
- SI units throughout, in the form `12 kW`, `450 °C`, `3.2 m`. Imperial values may follow in parentheses.
- Number every figure and table ("Figure 2", "Table 1") and give each a caption.
- State every assumption in the calculation that depends on it.
- Put safety notes in a blockquote starting with **Safety:**.

## 5. Visual identity

| Element | Specification |
| --- | --- |
| Typeface | IBM Plex Sans for text, IBM Plex Mono for code and values (SIL Open Font License, bundled in `.kit/fonts`) |
| Ink | `#111827` |
| Secondary text | `#4B5563` |
| Rules and grid | `#D1D5DB` |
| Accent (one only) | `#0F766E` teal |
| Document page | US Letter, 20 mm margins |
| Drawing sheet | ANSI B landscape (431.8 x 279.4 mm) |
| Footer | Document ID, version, status, license and designmolecule.com on every page |

## 6. Drawing and sketch conventions

- Units are millimeters unless the title block says otherwise.
- Third-angle projection, marked with the symbol in the title block.
- Line weights: visible outlines 0.5 mm, hidden lines 0.25 mm dashed, center lines 0.18 mm chain.
- The title block contains the project, title, drawing number, revision, scale, units, projection, sheet, author, date, material or notes, and license.
- Every sheet and every render names the project and its GitHub repository (from `repo:` in `project.yaml`), at the top of the sheet and in the title block, so a printed or forwarded sheet is never anonymous.
- The drawing title names the device, not only the drawing type (for example "Handheld near-infrared resin scanner: general arrangement").
- Every view label states its scale and viewing direction (for example "Scale 1:1; side elevation looking along +Y"), and every isometric or render states where it is seen from.
- Orthographic views generated with `add_ortho` carry overall dimensions (length and depth on the top view, height on the front view) and ISO 128 centre lines on cylinders; hidden lines are dashed. Tolerances are not shown before TRL 4.
- Sheets are exported as SVG, PDF and a 300 dpi PNG.
- The revision table in the top right of the sheet lists every revision.
- Concept sketches use the same sheet and title block and carry the label "CONCEPT, NOT FOR FABRICATION".
- Geometry comes from `cad/src/*.py` (build123d). Sheets are generated by `.kit/drawing.py` and never edited by hand.

## 7. Project codes

| Code | Project | Code | Project | Code | Project |
| --- | --- | --- | --- | --- | --- |
| TBK | ThermaBrick | PCF | PicoFlow | HLT | HelioLite |
| CCB | CharCube | DRN | DustRunner | TRT | TremorTrace |
| STC | StepCue | FXH | FlexHand | CPD | ColdPod |
| SCL | SunClave | STR | SteamRoot | GGD | GrainGuard |
| SDL | SeedLine | ZBX | ZeerBox | RMS | RootMesh |
| DWD | DewDrive | SSK | StillStack | PPR | PotPress |
| WWT | WaterWatch | LMF | LumaFlow | FCL | FieldCell |
| CNP | ConePro | CVC | CulvertCrawl | EGD | EmberGuard |
| SNF | SnapFrame | CGM | CargoMule | SCM | StepClimber |
| SWC | SwapCell | PLP | PalletPilot | FTK | FlatTrike |
| WWK | WaterWalker | GRR | GrowRider | SSP | SunSpoke |
| SGN | StepGen | PBX | PowerBox | WML | WasteWise-ml |
| WSC | WasteWise Scan | RFE | ReflowEconomy | | |
| OHP | Portfolio-wide | | | | |

## 8. Build and publish

- `python .kit/render.py` checks every controlled document and renders it to `docs/pdf/<doc_id>_v<version>.pdf`.
- `python .kit/drawing.py` (called from each project's `cad/src/sheets.py`) builds drawing sheets as SVG and PDF in `cad/drawings/`.
- The GitHub Action in `.github/workflows/docs.yml` runs the checks on every push and attaches PDFs to a GitHub Release whenever a release tag is pushed.
- Public releases follow section 14: `python .kit/release_gate.py` must pass, and the release tag is `v0.<TRL>.0` (for example `v0.3.0` at TRL 3).

## 9. Technology Readiness Level (TRL)

Each project states its maturity as a Technology Readiness Level on the NASA and US DOE 1 to 9 scale. The TRL rates this specific design, not the underlying technology. A sand battery is commercial elsewhere, but a new sand battery design starts at TRL 2 until evidence shows otherwise.

| TRL | Definition | Evidence the repo must contain |
| --- | --- | --- |
| 1 | Basic principles observed | Problem statement (PRB) |
| 2 | Technology concept formulated | Draft precis (PRC) and requirements (REQ) |
| 3 | Analytical or experimental proof of concept | Calculation note (CAL), working build123d model with STEP export, drawing sheet (DWG), priced BOM with every unit cost filled in, prototype build plan (BLD) with pictures, `design_state: constructable` |
| 4 | Components validated in the lab | Test report (TST) with `environment: lab`, build log entries |
| 5 | Validated in a relevant environment | Test report (TST) with `environment: relevant` |
| 6 | System prototype demonstrated in a relevant environment | Precis at version 1.0 or later with status Released, a drawing at a lettered revision (Rev A or later), and a system-level TST with `environment: relevant` |
| 7 to 9 | Operational demonstration through proven in service | Beyond portfolio scope; claim only with a named deployment partner and evidence |

Rules:

- `project.yaml` records `trl` (current level), `trl_target` (the level the current effort aims for) and `trl_evidence` (the files that support the claim).
- `python .kit/render.py --check` fails if the evidence for the claimed TRL is missing. CI runs this check on every push.
- Documentation alone cannot go past TRL 3. TRL 4 and above require hardware and a test report.
- TRL and visibility are independent. A repo can be public at TRL 3 as a documented design ready to build.
- A change of TRL is recorded in the build log with the date and the evidence that justified it.

## 10. Portfolio phase and TRL cap

`.kit/PHASE.yaml` sets the current phase. During the **populate** phase every repo is capped at **TRL 3**: `trl` and `trl_target` may not exceed 3, and the check fails if they do. Every repo targets the cap: `trl_target` must equal 3, so a new repo is taken all the way to TRL 3 (scaffold, populate and advance, see `/to-trl3`). Work that belongs to TRL 4 or later (building or testing hardware, test articles, test plans and reports, build-log entries, purchasing lists, PCB layouts) must not be started. The prototype build plan (BLD, section 18) is TRL 3 paper work and is required. Where it already exists it is kept, flagged in the check output, and not extended. Only Amish changes `PHASE.yaml`.

Every repo carries a `CLAUDE.md` with the working rules for AI sessions: the TRL cap, decision rights (nothing is recorded as decided unless Amish decided it), one step per session, and a mandatory `docs/REVIEW.md` before stopping.

## 11. Concept media

Every repo at TRL 2 or above explains its idea visually. Media are generated from a build123d massing model with `.kit/concept.py`, never drawn by hand, so they stay in step with the design.

| File | Required | Purpose |
| --- | --- | --- |
| `media/hero.png` | TRL 2+ | Shaded isometric render with a 1.75 m person for scale; the website card image |
| `media/concept-blueprint.png` and `.pdf` | TRL 2+ | Blueprint concept sheet: orthographic and isometric views, scale, key figures, title block |
| `media/model.glb` and `media/viewer.html` | TRL 2+ | Interactive 3D viewer (glTF plus model-viewer) for the website |
| `media/cutaway.png` | When the inside matters | Section view showing internal parts |
| `media/exploded.png` | Recommended | Exploded view with numbered callouts matching the BOM |
| `media/flow.png` | When energy or material moves | System, energy or material flow diagram with losses |

Session commands in `.claude/commands/` (`/populate`, `/advance-trl3`, `/rein-in`, `/refresh-media`) carry the standard prompts, so every Claude Code session starts from the same instructions.

At TRL 2 a massing model is enough: correct overall proportions and main components. All concept media carry "CONCEPT, NOT FOR FABRICATION". The check warns when required media are missing at TRL 2 and fails at TRL 3.

## 12. Product renders

Every repo at TRL 3 shows the product as it would look, not only as a massing model.

- `cad/src/product_model.py` is the appearance model. It defines `product_parts()` (named parts with a shape and a material), `TITLE` ("Name: what it is") and `RENDER_VIEWS`. It is for renders only: every main dimension comes from `cad/src/model.py`, never typed in again.
- Where the appearance model departs from `model.py` (a chamfer, a label, a fastener drawn for realism), record the deviation in `docs/REVIEW.md` as "Proposed, awaiting Amish".
- Scale comes from context, not from a floating figure: a hand or forearm for handheld objects, and the posed mannequin (`mannequin()` in `.kit/context_parts.py`: stand, walk, push, ride, sit, reach) for anything a person uses at body scale.
- Renders are made with `.kit/export_views.py` (one scene per view) and `.kit/photoreal.py` (Blender Cycles), then captioned with `.kit/photo_caption.py`. Files are `media/render-<view>.png`; `media/render-hero.png` is required.
- Every caption names the project, the repository and the viewing direction, and carries "CONCEPT, NOT FOR FABRICATION".
- Captions never sit on the render. `.kit/photo_caption.py` adds a header band (title, concept label, repository) above the render and a footer band (view note) below it, wraps every line to the image width, and steps the font down to a floor before adding a line.
- The README opens with `media/render-hero.png`.
- Software-only and scene repositories (no single product) may use a scene render as the hero instead of a product model.

## 13. Storefront images

Two images, both made from `media/render-hero.png` by `python .kit/cards.py .`:

| File | Size | Purpose |
| --- | --- | --- |
| `media/card.png` | 800 x 800 | Square thumbnail for the organization profile page |
| `media/social-preview.png` | 1280 x 640, under 1 MB | GitHub social preview, shown when a repository link is shared |

- The social preview shows the area, name, one-line description, the first sentence of the pitch, the brand line and the repository address. Design Molecule repos read "Design Molecule · open hardware concept, TRL n"; OpenRatio repos read "OpenRatio · research and educational prototype, TRL n".
- GitHub has no API for the social preview. Upload it under the repository's Settings, Social preview, on release day.
- Regenerate both images whenever `render-hero.png` changes.

### Image quality

Every render, card and social preview must be clear and readable. `python .kit/image_qc.py` checks each one, and the release gate blocks on any failure:

| Check | Rule |
| --- | --- |
| Layout | Made by the current `photo_caption.py` or `cards.py`, which store the text layout in the PNG |
| Text inside the image | Every line at least 1.2 % of the image width from each edge; nothing runs off the side |
| No overlap | No line of text touches another line, and no caption text sits on the render |
| Text size | Render captions at least 1.05 % of the image width in pixel height (17 px at 1600 px); social preview text at least 16 px |
| Resolution | Renders at least 1200 px wide; card 800 x 800; social preview 1280 x 640 and under 1 MB |
| Sharpness | The render is not blurred or upscaled (edge sharpness at least 15 on the `image_qc.py` scale) |

Long titles and notes wrap to more lines rather than shrinking below the floor. The social preview shortens the pitch sentence with an ellipsis only if it cannot fit at the smallest size.

## 14. Public release

A repository goes public only when Amish approves it, and only after `python .kit/release_gate.py` passes. The gate checks:

1. `render.py --check` passes (document control, TRL cap, concept media).
2. Storefront: hero render, card, social preview under 1 MB, README leading with the hero, and every image passing the image quality check (section 13).
3. Issue templates in `.github/ISSUE_TEMPLATE/`: question, build report, design suggestion. The build report template restates that the design is a TRL 3 concept, not released for fabrication (OpenRatio: a research and educational prototype, not a medical device).
4. `CITATION.cff` valid, with an author ORCID.
5. License files match `project.yaml`.
6. No em dashes in the repository's own text.
7. BioMedical and OpenRatio repos use soft, non-clinical wording: "research and educational prototype, not a medical device".
8. No secrets anywhere in the history (gitleaks).
9. No links to sibling repositories that are still private.
10. REUSE files present (`REUSE.toml`, `LICENSES/`, `.github/workflows/reuse.yml`) and `reuse lint` passes (section 16).
11. `CITATION.cff` names exactly one license, because Zenodo rejects a list (section 17).

It warns, without blocking, when the README lacks a Safety heading or a "not for fabrication" statement, when `CITATION.cff` has no DOI yet, and when the README lacks the Zenodo DOI, REUSE or Software Heritage badge, so a person can confirm.

On release day, per repository:

- A signed, annotated tag `v0.<TRL>.0` on `main`.
- A GitHub release with short notes (what it is, TRL, status, licenses, how to cite) and a design pack, `<repo>-v0.<TRL>.0-design-pack.zip`, holding `cad/step`, `cad/drawings`, `docs/pdf`, `bom`, README, licenses and `CITATION.cff`.
- Description from the first sentences of `pitch` (350 characters at most), website `https://designmolecule.com` (OpenRatio: `https://openratio.ai`), topics from `project.yaml`.
- Before the first release, the repository is switched on in Zenodo (section 17), so the release is archived and gets a DOI.
- Visibility switched to public last, after the release exists.
- The social preview uploaded and the organization profile updated with the new cards.
- After the release: the concept DOI written to `CITATION.cff` and a Software Heritage save requested (section 17).

The internal working files (`CLAUDE.md`, `.kit/CLAUDE.md`, `.claude/commands/`, `docs/REVIEW.md`) stay public, and open "Proposed, awaiting Amish" items stay visible as open questions (Amish, 2026-09-27).

## 15. Authorship, citation and signing

- Amish Chadha is the author of every design, ORCID 0009-0000-8079-7141. Commits are authored as Amish Chadha <amish@designmolecule.com>.
- `CITATION.cff` lists Amish (with ORCID) first, then any credited contributors; `CONTRIBUTORS.md` and the README Credits section agree with it.
- `CITATION.cff` names one license: the hardware license (CERN-OHL-S-2.0), or the software license in a software-only repository. The full split between hardware and software licenses lives in `REUSE.toml` and the README. Once the repository is archived, `CITATION.cff` carries the concept DOI in `doi:`.
- Work done with Claude carries the trailer `Co-Authored-By: Claude <noreply@anthropic.com>` (with the model name), and the README Credits section says designs are developed with AI assistance.
- Every commit and tag pushed to GitHub is signed with Amish's SSH signing key, so GitHub shows it as Verified. Commits prepared elsewhere are re-signed on Amish's Mac before they are pushed.
- Once a repository is public, its history is never rewritten.

## 16. Licensing metadata (REUSE)

Every file states its copyright and license in a machine-readable way, following the REUSE Specification 3.3 (https://reuse.software). A repository is set up with:

```
python .kit/archive.py reuse
```

This writes three things and adds the REUSE and Software Heritage badges to the README badge line:

- `REUSE.toml`, built from the licenses in `project.yaml`. Everything is under the hardware license by default. Scripts, firmware, notebooks, web viewers, workflows and agent commands are under the software license. `cad/` and `electronics/` stay under the hardware license even where they are written as Python. The bundled IBM Plex fonts are OFL-1.1 (IBM Corp.). Copyright is "<first commit year> Amish Chadha".
- `LICENSES/`, with the full text of each license used (`reuse download`). The root `LICENSE` and `LICENSE-SOFTWARE` files stay for GitHub's license detection.
- `.github/workflows/reuse.yml`, which runs the REUSE check (fsfe/reuse-action) on every push and drives the README badge.

A new kind of file that falls outside these rules gets a new annotation in `REUSE.toml` rather than a header comment. `reuse lint` must pass before every commit that adds files, and the release gate enforces it.

## 17. Archiving and DOI (Zenodo and Software Heritage)

Every public repository is archived twice, so the design stays citable and retrievable if GitHub changes.

Zenodo (a citable DOI for each release):

1. Amish's Zenodo account is linked to GitHub. Before the first release, Amish switches the repository on in Zenodo (Account, GitHub). Only Amish changes Zenodo or GitHub settings.
2. Run `python .kit/archive.py zenodo`: it makes sure `CITATION.cff` names one license and adds the Zenodo DOI badge, which uses the GitHub repository ID and always points at the latest version. Zenodo reads its metadata (title, authors with ORCID, license, keywords) from `CITATION.cff`, and rejects the whole archive when that file lists several licenses.
3. Publish the GitHub release (section 14). Zenodo archives it within minutes and mints two DOIs: a version DOI for that release and a concept DOI that stands for all versions.
4. Check the Zenodo record: title, author and ORCID, license, keywords. If Zenodo shows "Citation metadata load failed", fix `CITATION.cff`, validate it with cffconvert and publish a new patch release (for example `v0.3.2`); a failed release is never re-used.
5. Run `python .kit/archive.py zenodo --doi <concept DOI>` and commit, so GitHub's "Cite this repository" and every future archive carry the concept DOI. Every later release gets its own version DOI automatically; the concept DOI never changes.

Software Heritage (permanent source archive):

1. After the repository is public, request a save at https://archive.softwareheritage.org/save/ (origin type git, the repository URL). Anonymous requests are limited to about ten an hour, so batches are spread out.
2. The Software Heritage badge on the README resolves once the save is accepted and ingested. Later pushes are picked up by its regular crawl.

OpenRatio repositories follow the same steps when Amish approves their release.

## 18. Prototype build plan (BLD) and the constructable design

### Two design states

A design moves through two states, recorded as `design_state` in `project.yaml`:

- **Concept**: the design shows what the product does and that it works on paper (TRL 2 and the calculations of TRL 3). Parts may be simplified shapes that have never been checked for how they are made or how they join.
- **Constructable**: every part can be made with the stated process and material, and every part fits and fastens to the parts next to it. Nothing is left as a shape that cannot be cut, cast, bent, printed, machined or bought.

A repo reaches TRL 3 only when its design is constructable and its build plan shows how. Writing the build plan is how the design is made constructable: when a part cannot be made or cannot fit as modelled, change the model so it can (Amish, 2026-09-30: "fix the design assumptions to match and be physically feasible"), keep what the concept does, and record every change in a decision record "Design for construction" (DDR) and in the plan. Changes that alter what the product does, its pitch or its safety case are proposed, not made.

### What the build plan is

`docs/05-build-plan.md` (`PRJ-BLD-001`) tells a capable maker how to build the first proof-of-concept prototype, in order, component by component, and shows it in pictures. It is written before anything is built, states "Plan, not yet built" under the title and never claims results. Building and testing to it is TRL 4 work.

### Writing rules

- **Plain English.** Say "the steel plate the jack stands on", not a model parameter or variable name. No code identifiers, function names, parameter names or file paths in the body of the plan. Give sizes as numbers with units ("a 62 mm hole, centred 100 mm up from the bottom edge"). The only place file names appear is the closing "Where the numbers come from" list.
- **Pictures first.** Every component and every assembly step has a picture. A reader should be able to build from the pictures, with the words explaining what the pictures cannot show (order, force, tolerance, checks).
- **By component, in build order.** Each component is made and checked before the step that needs it.
- **Cost is not the focus.** One line in the overview may state the parts cost from the BOM; there is no cost or time section.

### Sections, in order

1. **What you are building**: the overview picture (every component pulled apart and numbered in build order) and one short paragraph.
2. **What changed to make it buildable**: a table of each change from the concept (what the concept had, what the constructable design has, why), with a picture where the change is visible. "None" if nothing changed.
3. **Making the components**: one subsection per made component, in build order, each with:
   - its making sketch (three views with overall sizes, a 3D view, where it goes, making notes), `cad/drawings/PRJ-DWG-1NN`;
   - what it is and what it is made from (material, stock size);
   - how to make it, as numbered steps (mark out, cut, drill, bend, weld, cast, print, machine, finish), with the sizes that matter;
   - how it fits the parts next to it: a close-up picture of the joint, which faces touch, what holds them (bolt, weld, pin, clip, glue), the gap or fit needed, and which side goes where;
   - the check before moving on.
   Bought components get a short subsection: what to buy (specification, not brand), and what to do to it (drill, trim, fit).
4. **Putting it together**: numbered assembly steps, each with a step picture (parts already fitted in grey, the part being fitted in colour with an arrow showing the way it goes in), the fasteners, and any hold point.
5. **First checks**: fit, movement, first power or first load, each tied to a requirement ID with a pass criterion. The plan lists them; a TRL 4 test report records them.
6. **Safety stops**: points where work stops (before energising, pressurising, loading, lifting or operating) and what must be true to carry on.
7. **Tools, skills and workspace.**
8. **Where the numbers come from**: the model, drawings, calculation note and BOM, by file name.
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

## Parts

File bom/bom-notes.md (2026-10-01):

# BOM notes

All costs are indicative USD prices for a single prototype, not quotes. Suppliers are named by type until parts are selected.

- Line numbers 1 to 12 match the callouts in `media/exploded.png`. Line 13 (hardware and consumables) has no callout. Lines 14 (front bezel) and 15 (side plates and small made parts) were added on 2026-09-30 to make the design buildable (CVC-DDR-003); in the exploded view each is shown with the parts it carries (bezel with the LEDs, callout 6; side plates with the tracks, 2; tray with the electronics, 4; fin bracket with the laser, 7; camera mount with the camera, 5).
- **2026-09-30, design for construction (CVC-DDR-003).** 15 lines, total **$1,034** against `budget_usd: 910`, $124 over: R12 not met. The added parts are the bezel (line 14, $22), side plates, tray, fin bracket and camera mount (line 15, $10), and price increases on lines 1 ($70 to $78), 4 ($110 to $113), 7 ($47 to $55), 8 ($18 to $22), 10 ($125 to $168), 11 ($185 to $205) and 13 ($30 to $40). Raising the budget is proposed, awaiting Amish; `budget_usd` is unchanged.
- Before 2026-09-30, every line was priced and the total was **$906** (13 lines, line 9 at 60 m), checked by `docs/04-calcs/sizing.py` against `budget_usd: 910` in `project.yaml`. The budget of $900 was decided by Amish on 2026-09-25 (CVC-DDR-001) and raised to $910 on 2026-09-26 to cover the priced BOM (CVC-DDR-002). The total was $901 at CVC-CAL-001 v0.1, and Amish accepted that $1 as within pricing uncertainty, to revisit with real quotes (CVC-DDR-002). The changes he approved at the same time add $5: the ballast plate grows to 230 x 80 x 14 mm (line 8, $15 to $18) and the laser boom is 100 mm longer (line 7, $45 to $47). R12 was recorded as not met by $6 in CVC-CAL-001 v0.2 and is met at $910 in CVC-CAL-001 v0.3.
- The softest prices are the machined hull (line 1), the hybrid tether (line 9) and the conical mirror (line 7). Each could move the total by $20 to $80.
- TRL 3 specification changes, with no price change: camera run at 50 frames per second with a circular fisheye (line 5); fuse split into 10 A at the battery and 2 A on the 48 V output (line 11).
- The operator laptop is assumed to be the user's own and is not included. No SwapCell pack is used (LiFePO4 surface battery decided); if a SwapCell input is added later, the pack is priced once in the SwapCell repo and excluded from this kit, per Amish's 2026-09-25 portfolio rule.

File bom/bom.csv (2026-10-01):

item | qty | spec | supplier | unit_cost_usd | make_buy | notes
1 Sealed hull and lid | 1 | 6061 aluminium body machined from a 240 x 88 x 80 mm block: 240 x 88 x 74 mm outside, 4 mm side and rear walls and floor, 10 mm front wall bored 50 mm for the camera, 12 mm wide inner rim 10 mm deep at the top with an O-ring groove and ten M4 tapped holes, drive pads and idler bosses inside the side walls with 16 mm lip seal counterbores, four floor pads; flush 6 mm lid 240 x 88 mm with ten M4 screws and an M10 pressure-test plug; M10 IP68 tether penetrator in the rear wall 77 mm up; about 1.26 kg (CVC-DDR-003) | Online CNC machining service or local machine shop | 78.00 | make | Indicative price; softest price in the BOM (a machined box may quote higher); rim, pads and thicker front wall added for construction (+$8, CVC-DDR-003); IP68 to 1 m is a target and not verifiable at TRL 3
2 Track modules (pair) | 1 | Two rubber track belts 36 mm wide (outer edges 170 mm apart, as before) over 70 mm drive sprockets and idlers at 200 mm centers; sprocket bored 8 mm D with a set screw; idler on an M6 shoulder bolt; the kit's own side plates are not used (made side plates are line 15) | Robot tank chassis kit supplier | 60.00 | buy | Indicative price; about 1.0 kg for belts and wheels (CVC-CAL-001); belts narrowed from 40 mm so a side plate fits between hull and belt (CVC-DDR-003)
3 Worm gear motors | 2 | 12 V self-locking worm gear motors (5840 class), about 80 rpm output, rated 1 N·m or more (0.84 N·m needed at the traction limit, CVC-CAL-001), Hall encoders, 8 mm D output shaft at least 38 mm long, two M4 tapped holes in the output face; 8 x 16 x 5 mm double lip shaft seal for each | Electronics or robotics distributor | 18.00 | buy | Indicative price; self-locking gearbox holds the crawler on a grade without power; shaft length and face holes to confirm when bought (CVC-DEC-001)
4 Electronics stack | 1 | Raspberry Pi 4 Model B 2 GB (hardware H.264 encoder) on four 4 mm spacers; deck on 20 mm M2.5 standoffs carrying a dual DC motor driver with current limit, 36 to 75 V input to 12 V buck converter, 12 to 5 V buck converter and 6-axis IMU; leak sensor; microSD card | Electronics distributor | 113.00 | buy | Indicative price (Pi about $45; converters about $25; driver about $12; IMU and leak sensor about $15; card about $10; deck plate and standoffs about $3)
5 Fisheye camera and dome port | 1 | 12 MP Sony IMX708 camera module with M12 lens mount, run at 2304 x 1296 and 50 frames per second; 180 degree class circular fisheye M12 lens with the image circle inside the 1296 px sensor height; 60 mm acrylic dome port with a 72 mm flange and O-ring; printed camera mount (line 15) | Camera module distributor (M12-mount IMX708 boards) and ROV parts supplier | 60.00 | buy | Indicative price; lens field and calibration set profiling accuracy (R5)
6 LED ring light | 1 | 8 x 1 W high-CRI white LEDs on 10 mm round aluminium boards (about 800 lm), potted in the front bezel (line 14), dimmable constant-current driver synchronized to the camera | LED supplier | 25.00 | buy | Indicative price; dimmed on laser frames; stock 10 mm LED boards replace the concept's 88 mm ring board (CVC-DDR-003)
7 Laser ring projector on boom | 1 | Class 2 (1 mW or less) 520 nm laser diode module (12 mm body) and a 90 degree conical mirror (20 mm base); clear acrylic boom tube 18 x 12 mm about 235 mm long; clear acrylic fin 8 mm; machined aluminium diode housing; clear acrylic window tube 26 x 22 mm; aluminium end cap; ring plane 300 mm ahead of the dome center | Optics and laser module suppliers | 55.00 | buy | Indicative price; conical mirror price is uncertain; fin, window and end cap added for construction (+$8, CVC-DDR-003)
8 Ballast skid plate | 1 | Steel plate 255 x 88 x 14 mm (about 2.45 kg), square nose with edges broken, 8 mm above the track contact line; six M4 tapped holes in its sides for the side plates, two in its nose for the fin bracket, an M8 tapped hole near the rear for the eye bolt | Local fabricator or steel stockholder | 22.00 | make | Indicative material and machining cost; also protects the hull bottom; widened and lengthened so the side plates and eye bolt can fix to it, turned-up lip replaced by a square nose (CVC-DDR-003); was 230 x 80 x 14 mm (CVC-DDR-002)
9 Tether with strain relief | 60 | Hybrid cable per meter: 2 twisted pairs (100BASE-TX) plus 2 x 0.75 mm² class 5 power conductors (26 ohm/km), aramid strength member of 1 kN or more, PU jacket about 7 mm OD, about 55 g/m (estimate); strain relief and bend restrictor at the crawler; strength member tied to the eye bolt (line 13) | Cable supplier (ROV or industrial hybrid cable) | 2.00 | buy | Indicative price per meter; custom hybrid cable may cost more
10 Tether reel with slip ring and payout counter | 1 | Reel: drum cut from 225 mm PVC pipe 104 mm long, two 320 mm flanges of 6 mm HDPE on four M6 tie rods, two 20 mm flange shaft hubs, 20 mm hollow aluminium axle; frame: two 6 mm aluminium side frames on three spacer tubes and M6 tie rods, two 20 mm flanged bearings, hand crank, M8 knob brake; 6-circuit slip ring rated for 100 Mbit/s Ethernet with an anchor bracket; 50 mm payout wheel with a 600-count rotary encoder and a USB encoder reader, on a bar from the front spacer | Reel from local fabricator; slip ring and encoder from electronics distributor | 168.00 | make | Indicative price (slip ring about $70; reel, frame, bearings and hubs about $73; encoder wheel and USB reader about $25); frame, bearings and counter bracket added for construction (CVC-DDR-003)
11 Surface control box | 1 | Rugged case about 410 x 330 x 175 mm, not drilled; drop-in chassis of a 6 mm plywood base board, four 20 mm aluminium posts and a 2 mm aluminium panel; 12.8 V 20 Ah LiFePO4 battery with BMS laid on its side and strapped to the base board; 12 to 48 V 100 W boost converter; 10 A fuse at the battery and 2 A fuse on the 48 V tether output; latching emergency stop; tether current monitor with 1.5 A overcurrent cutoff; tether, Ethernet and charge connectors and power switch on the panel | Battery and electronics distributors; case from outdoor retailer | 205.00 | buy | Indicative price (battery about $90; case about $45; boost about $20; stop, fuses and monitor about $30; chassis about $20); fuse split changed at TRL 3 because peak battery current is about 5.4 A (CVC-CAL-001)
12 Operator gamepad | 1 | USB gamepad for driving; operator laptop is the user's own and not in the cost | Electronics retailer | 20.00 | buy | Indicative price
13 Hardware and consumables | 1 | O-rings (lid, dome, six screw seals), spare penetrator seals, stainless fasteners, M8 forged eye bolt for the tether's strength member, threadlocker, silicone grease, potting epoxy, heat-shrink, cable ties | Local hardware shop | 40.00 | buy | Indicative price; no exploded-view callout; eye bolt and added screws (+$10, CVC-DDR-003)
14 Front bezel | 1 | Machined 6061 ring 88 mm outside, 62 mm inside, 10 mm thick; 73 mm recess 5 mm deep on the back for the dome flange; eight 10.5 mm LED pockets 3 mm deep on a 75 mm circle; four 4.5 mm screw holes; potted after the LEDs are wired | Online CNC machining service or local machine shop | 22.00 | make | Indicative price; added for construction: clamps the dome on its O-ring and holds the LEDs (CVC-DDR-003)
15 Side plates and small made parts | 1 | Two track side plates 230 x 53 x 3 mm (5052 or 6061 aluminium); electronics tray 104 x 62 x 2 mm aluminium; fin bracket from 30 x 30 x 3 mm aluminium angle; printed camera mount 56 x 48 x 4 mm (PETG or ASA) | Metal stockholder; 3D printer | 10.00 | make | Indicative material cost; added for construction (CVC-DDR-003)

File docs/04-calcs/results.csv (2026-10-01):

quantity | value | unit
crawler width over tracks | 170 | mm
crawler height over lid screws | 106 | mm
crawler length, rear strain relief to cone mirror | 611 | mm
track length (sprocket to idler, over belt) | 270 | mm
300 mm pipe: track contact line above invert | 26.4 | mm
300 mm pipe: camera axis above invert | 88.4 | mm
300 mm pipe: least radial clearance, crawler to wall | 50 | mm
600 mm pipe: track contact line above invert | 12.3 | mm
600 mm pipe: camera axis above invert | 74.3 | mm
600 mm pipe: least radial clearance, crawler to wall | 66 | mm
900 mm pipe: track contact line above invert | 8.1 | mm
900 mm pipe: camera axis above invert | 70.1 | mm
900 mm pipe: least radial clearance, crawler to wall | 69 | mm
track edge contact angle in 600 mm pipe | 16.5 | deg
normal load factor (sum of normals / weight), 600 mm | 1.043
normal load factor, 300 mm | 1.214
normal load factor, 900 mm | 1.018
mass: Hull body and lid (model volume, 6061) | 1.26 | kg
mass: Track belts, sprockets, idlers | 1.00 | kg
mass: Side plates (model volume, 6061) | 0.19 | kg
mass: Worm gear motors (2 x 0.35 kg) | 0.70 | kg
mass: Electronics stack | 0.20 | kg
mass: Electronics tray and camera mount (model volume) | 0.05 | kg
mass: Camera, dome, LEDs | 0.15 | kg
mass: Front bezel (model volume, 6061) | 0.06 | kg
mass: Laser projector: fin, boom, head (model) plus diode and mirror 0.02 kg | 0.13 | kg
mass: Ballast plate (model volume, steel 7.85 kg/L) | 2.45 | kg
mass: Fasteners, eye bolt, seals, penetrator, strain relief | 0.45 | kg
crawler mass | 6.63 | kg
displaced volume, fully submerged | 2.87 | L
net submerged mass | 3.77 | kg
fraction of dry normal load left when submerged | 0.57
design case: water depth above track contact line (600 mm) | 138 | mm
design case: crawler fully submerged (1 = yes) | 1
kit mass: Crawler | 6.6 | kg
kit mass: Tether, 60 m | 3.3 | kg
kit mass: Reel, frame, slip ring, counter (made parts from the model) | 4.5 | kg
kit mass: Surface box (case 3.0 kg, LiFePO4 2.5 kg, electronics, chassis from the model) | 7.6 | kg
kit mass: Gamepad | 0.2 | kg
whole kit mass | 22.2 | kg
reel with tether | 7.8 | kg
heaviest single item | 7.8 | kg
tether weight in air | 0.540 | N/m
tether weight submerged | 0.162 | N/m
dry 600 mm, uphill (enter at outlet): usable traction | 32.5 | N
dry 600 mm, uphill (enter at outlet): track resistance | 10.2 | N
dry 600 mm, uphill (enter at outlet): grade force (+ resists) | 3.25 | N
dry 600 mm, uphill (enter at outlet): water drag (+ resists) | 0.00 | N
dry 600 mm, uphill (enter at outlet): tether drag per meter | 0.296 | N/m
dry 600 mm, uphill (enter at outlet): REACH at 20 % reserve | 64 | m
dry 600 mm, downhill (enter at inlet): usable traction | 32.5 | N
dry 600 mm, downhill (enter at inlet): track resistance | 10.2 | N
dry 600 mm, downhill (enter at inlet): grade force (+ resists) | -3.25 | N
dry 600 mm, downhill (enter at inlet): water drag (+ resists) | 0.00 | N
dry 600 mm, downhill (enter at inlet): tether drag per meter | 0.242 | N/m
dry 600 mm, downhill (enter at inlet): REACH at 20 % reserve | 106 | m
design case wet: submerged, 0.5 m/s flow, uphill: usable traction | 18.5 | N
design case wet: submerged, 0.5 m/s flow, uphill: track resistance | 5.8 | N
design case wet: submerged, 0.5 m/s flow, uphill: grade force (+ resists) | 1.84 | N
design case wet: submerged, 0.5 m/s flow, uphill: water drag (+ resists) | 4.19 | N
design case wet: submerged, 0.5 m/s flow, uphill: tether drag per meter | 0.089 | N/m
design case wet: submerged, 0.5 m/s flow, uphill: REACH at 20 % reserve | 75 | m
design case wet: submerged, 0.5 m/s flow, downhill: usable traction | 18.5 | N
design case wet: submerged, 0.5 m/s flow, downhill: track resistance | 5.8 | N
design case wet: submerged, 0.5 m/s flow, downhill: grade force (+ resists) | -1.84 | N
design case wet: submerged, 0.5 m/s flow, downhill: water drag (+ resists) | -1.21 | N
design case wet: submerged, 0.5 m/s flow, downhill: tether drag per meter | 0.073 | N/m
design case wet: submerged, 0.5 m/s flow, downhill: REACH at 20 % reserve | 216 | m
dry uphill reach with no traction reserve | 92 | m
wet uphill reach if submerged track friction is 0.45 | 23 | m
wet case, reversing upstream with reel winding: force margin | 6.7 | N
extra steel ballast for 50 m wet uphill | 0.00 | kg
stationary in 0.5 m/s flow: water drag | 2.5 | N
stationary submerged: static friction available | 23.1 | N
sprocket torque per motor at the dry traction limit | 0.84 | N m
top speed at 80 rpm | 0.29 | m/s
hold on 5 % with power off: grade force | 3.25 | N
hold on 5 %: static friction available | 40.7 | N
step climb, conservative rule (idler radius) | 35 | mm
step climb, friction bound r(1 + sin(atan mu)), mu = 0.6 | 53 | mm
step climb, friction bound r(1 + sin(atan mu)), mu = 0.4 | 48 | mm
pull, tracks locked, 50 m of tether, uphill of the crew | 59 | N
tether break strength | 1000 | N
safety factor on the locked-track pull | 17.0
stuck pull the 1 kN member can take at a factor of 5 | 200 | N
crawler loads while driving and profiling | 28.0 | W
tether loop resistance (2 x 60 m) | 3.12 | ohm
crawler input power | 30.8 | W
tether current | 0.67 | A
voltage at the crawler | 45.9 | V
tether copper loss | 1.40 | W
tether loss as share of boost output | 4.4 | %
boost output | 32.2 | W
battery output incl. surface electronics | 36.0 | W
peak: tether current | 1.25 | A
peak: voltage at the crawler | 44.1 | V
peak: tether voltage drop | 3.9 | V
peak battery current at 12.0 V (low charge) | 5.4 | A
tether loss if run at 24 V instead | 8.24 | W
usable battery energy | 230 | Wh
endurance, nominal | 6.4 | h
endurance, derated 20 % for cold and ageing | 5.1 | h
battery energy (nominal) | 256 | Wh
fisheye angular resolution (equidistant) | 0.139 | deg/px
300 mm: top of pipe angle off the camera axis | 35.2 | deg
300 mm, water 0 mm: mean diameter error (95th pct) | 0.24 | % of D
300 mm, water 0 mm: vertical diameter error (95th pct) | 0.25 | % of D
300 mm, water 0 mm: worst wall point error (95th pct) | 1.4 | mm
600 mm: top of pipe angle off the camera axis | 60.3 | deg
600 mm, water 0 mm: mean diameter error (95th pct) | 0.43 | % of D
600 mm, water 0 mm: vertical diameter error (95th pct) | 0.55 | % of D
600 mm, water 0 mm: worst wall point error (95th pct) | 4.1 | mm
600 mm, water 150 mm: mean diameter error (95th pct) | 0.44 | % of D
600 mm, water 150 mm: vertical diameter error (95th pct) | 0.57 | % of D
600 mm, water 150 mm: worst wall point error (95th pct) | 4.1 | mm
900 mm: top of pipe angle off the camera axis | 70.1 | deg
900 mm, water 0 mm: mean diameter error (95th pct) | 0.71 | % of D
900 mm, water 0 mm: vertical diameter error (95th pct) | 0.93 | % of D
900 mm, water 0 mm: worst wall point error (95th pct) | 9.0 | mm
900 mm, water 150 mm: mean diameter error (95th pct) | 0.74 | % of D
900 mm, water 150 mm: vertical diameter error (95th pct) | 0.97 | % of D
900 mm, water 150 mm: worst wall point error (95th pct) | 9.4 | mm
900 mm, water 150 mm, former 200 mm ring plane: vertical diameter error | 1.41 | % of D
300 mm: share of the ring hidden by the boom fin | 6.4 | %
900 mm: share of the ring hidden by the boom fin | 2.1 | %
900 mm, water 150 mm, without the fin (concept boom): vertical diameter error | 0.95 | % of D
profiles per second (laser on alternate frames) | 25 | 1/s
profile spacing at 0.15 m/s | 6 | mm
profile spacing at top speed | 12 | mm
ring irradiance on the wall, 900 mm pipe | 0.177 | W/m2
signal electrons per pixel on the ring (10 ms, f/2) | 272 | e-
shot-noise limited SNR | 16
pupil share of emitted power at 100 mm from the cone (7 mm pupil) | 11 | uW
video frame rate (LED frames of a 50 fps stream) | 25 | fps
video stream (1080p H.264) | 8 | Mbit/s
laser frames (1296 x 1296 grey JPEG, 1 bit/px) | 42 | Mbit/s
link use of about 94 Mbit/s usable on 100BASE-TX | 53 | %
LED luminous intensity (800 lm in a 120 deg cone) | 255 | cd
illuminance on the far wall of a 900 mm pipe (0.83 m) | 370 | lx
illuminance 2 m ahead down the pipe | 64 | lx
payout encoder resolution (50 mm wheel, 600 counts) | 0.26 | mm
R6 distance tolerance at 50 m (1 % or 0.2 m) | 0.5 | m
heat inside the hull | 11.0 | W
hull outer area | 0.095 | m2
hull rise over air, h = 8 W/(m2 K) | 15 | K
hull rise over water, h = 300 W/(m2 K) | 0.4 | K
water pressure at 1 m (IP68 target) | 9.8 | kPa
cost: crawler (items 1 to 8, 14, 15) | 481 | USD
cost: tether, reel and surface kit (items 9 to 12) | 513 | USD
cost: hardware and consumables (item 13) | 40 | USD
BOM lines | 15
BOM total | 1034 | USD
budget_usd | 910 | USD
margin (budget minus total) | -124 | USD

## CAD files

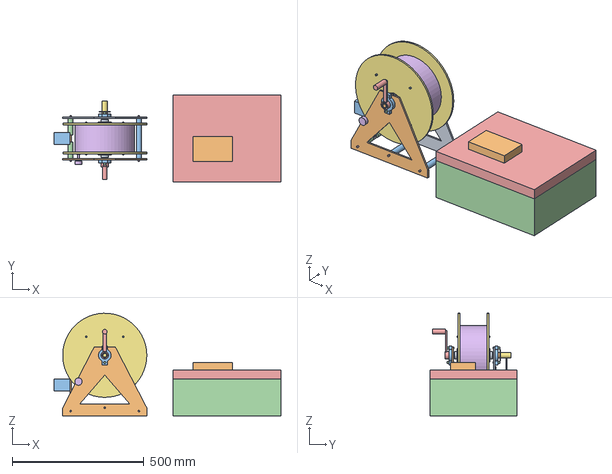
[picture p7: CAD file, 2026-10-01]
cad/step/culvertcrawl-surface-kit.step
863.0 x 330.0 x 389.9 mm

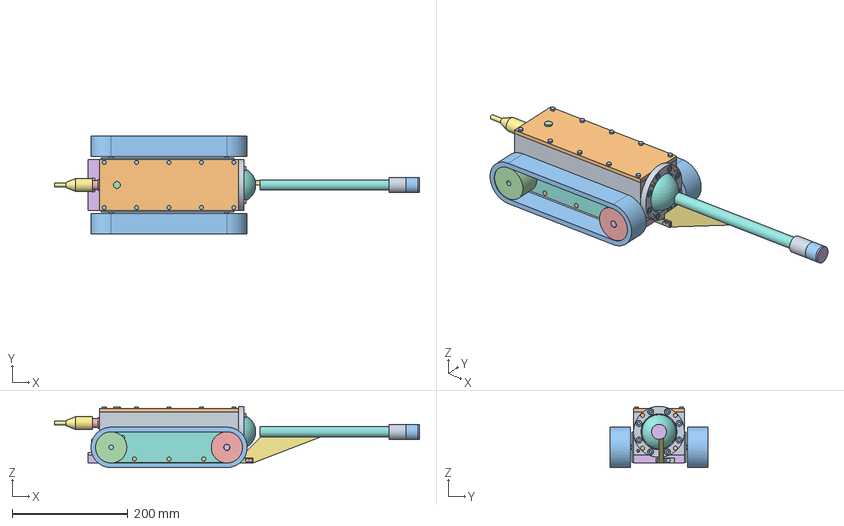
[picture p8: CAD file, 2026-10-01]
cad/step/culvertcrawl-crawler.step
631.0 x 170.0 x 105.9 mm

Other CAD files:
cad/stl/culvertcrawl-crawler.stl
cad/stl/culvertcrawl-surface-kit.stl

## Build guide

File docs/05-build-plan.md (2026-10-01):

---
doc_id: CVC-BLD-001
title: CulvertCrawl prototype build plan
project: CulvertCrawl
doc_type: Build plan
version: "0.2"
status: Draft
date: '2026-10-01'
author: Amish Chadha
license: CERN-OHL-S-2.0
revisions:
  - version: "0.1"
    date: '2026-09-30'
    author: Amish Chadha
    change: First build plan, with pictures by component and step; design made constructable (CVC-DDR-003)
  - version: "0.2"
    date: '2026-10-01'
    author: Amish Chadha
    change: Budget treated as a value-engineering target; cross-references updated
---

# CulvertCrawl prototype build plan

**Plan, not yet built.** How to build the first proof-of-concept prototype, component by component. Building and testing to it is TRL 4 work. Decisions still to be made are kept in the design decisions register ([docs/06-design-decisions.md](06-design-decisions.md)), not here.

## 1. What you are building

Figure 1. The crawler, every component pulled apart and numbered in build order

*Figure 1. The crawler: 16 components, pulled apart and numbered in build order.*

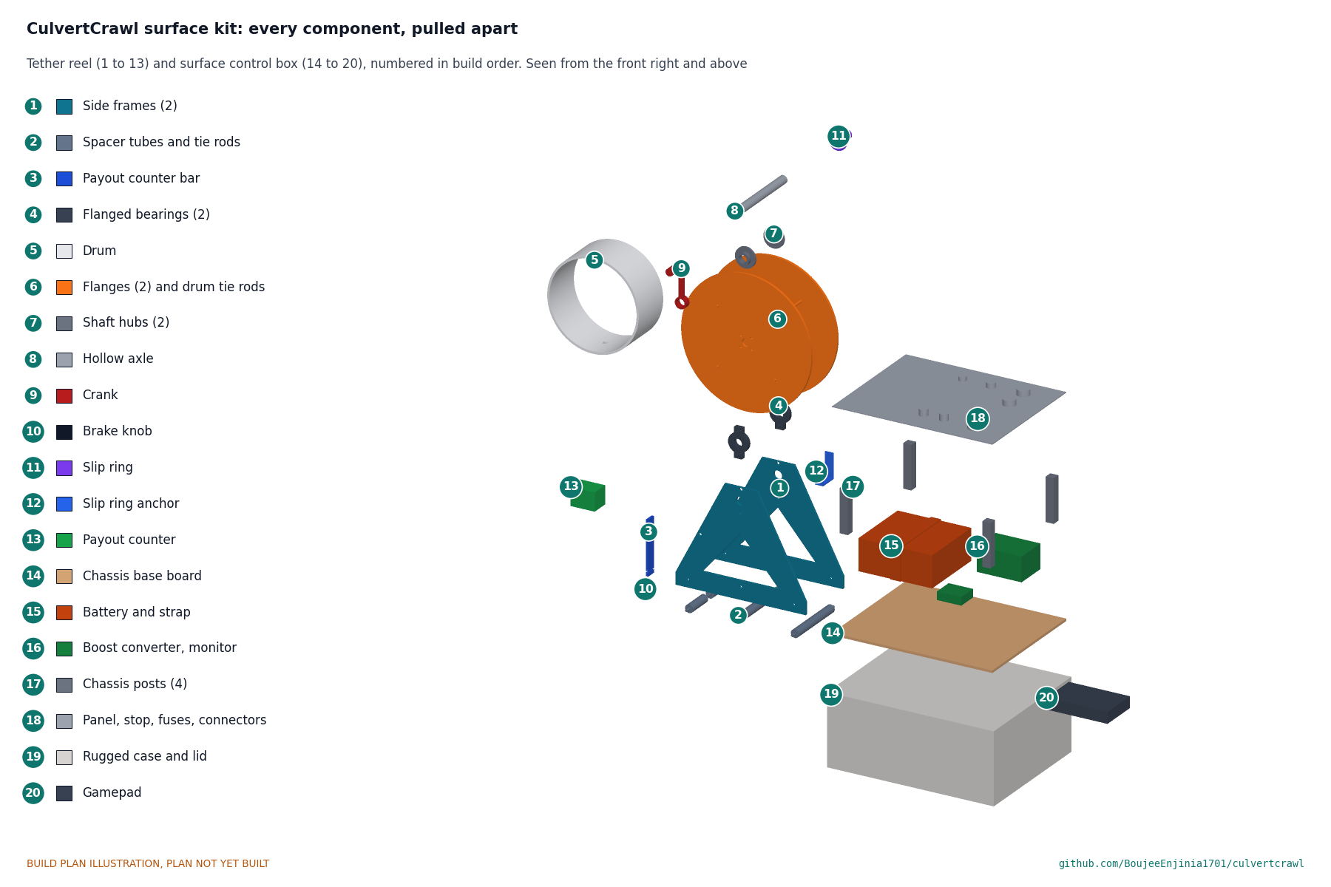
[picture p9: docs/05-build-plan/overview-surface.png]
Figure 2. The surface kit, every component pulled apart and numbered in build order


*Figure 2. The surface kit: the tether reel (1 to 13) and the surface control box (14 to 20).*

The prototype is a small tracked crawler, 611 mm long, 170 mm wide and 106 mm high, on a 60 m tether, with a hand-wound tether reel and a surface control box. The crawler is a sealed aluminium box on a steel skid plate, driven by two worm gear motors through rubber tracks; a fisheye camera looks forward through an acrylic dome, ringed by eight LEDs, and a laser at the end of a clear boom throws a ring of light onto the pipe wall 300 mm ahead. The box at the surface holds the battery, the 48 V supply, the fuses and the emergency stop. Most of the structure is made: the hull and lid are machined from aluminium block and plate, the ballast plate is cut and drilled from steel bar, the side plates, tray, brackets, reel frames and box panel are cut and drilled from sheet and bar, the boom, fin and window are cut from clear acrylic, the reel drum and flanges are cut from plastic pipe and sheet, and two small parts are 3D printed. Everything else (motors, tracks, camera, electronics, tether, slip ring, case, battery) is bought and fitted. The parts cost about $1,034 from the bill of materials, against a value-engineering target of $910.

Left and right are as seen from behind the crawler, looking the way it drives. Heights on the crawler are up from the track contact line (the flat ground the tracks stand on) unless a step says otherwise. Sizes are in millimetres; workshop tolerance is 0.5 mm unless a step says otherwise.

> **Safety:** The surface box holds a 12.8 V, 20 Ah lithium iron phosphate battery (about 256 Wh) and a 48 V supply. Keep the battery fuse out until section 6 says otherwise, and never charge a battery that is damaged, swollen or has been in water. The laser is Class 2: never look into the beam or through optics at it, and switch it off whenever the crawler is out of a pipe. The tracks and sprockets can trap fingers. Cut aluminium and steel edges are sharp; deburr everything and wear gloves for bar and sheet. Acrylic solvent cement and potting epoxy give off fumes; use them in a ventilated space with gloves and eye protection.

## 2. What changed to make it buildable

The concept showed what the crawler does; some of its parts could not be made or fixed as drawn. Each change below keeps what it does, and all of them are recorded in decision record CVC-DDR-003.

*Table 1. Changes from the concept.*

| Component | The concept had | The buildable design has | Why |
| --- | --- | --- | --- |
| Hull and lid | 4 mm walls; a lid overhanging by 3 mm with nothing to seal on or screw into | A rim 12 mm wide inside the top, with the O-ring groove and ten M4 screws; a flush lid; a 10 mm front wall (Figures 3, 4 and 5) | A 4 mm wall cannot carry both an O-ring groove and a tapped hole |
| Tracks | 40 mm belts 1 mm from the hull; side plates overlapping the hull walls, with no fixing | 36 mm belts with the same outer edge; made 3 mm side plates flat on the hull and ballast plate (Figures 10 and 11) | Room for a plate between hull and belt, without changing the crawler's width |
| Motors | Gearboxes through the rear wall; no fixing; no seal housing | Gearbox faces on drive pads inside the side walls, two screws each; lip seals in counterbores in the walls (Figure 11) | The motors are held by their own tapped faces; the seals are kept in by the side plates |
| Electronics | A converter block inside the motors; nothing fixed | A tray on four floor pads; the Pi on spacers; a deck on standoffs above it (Figure 14) | Everything fits and is screwed down |
| Camera and lights | Camera behind a solid wall; dome and LED ring floating | A bored front wall, a printed camera mount, and a machined bezel that clamps the dome and holds eight potted LEDs (Figure 18) | The dome is sealed on an O-ring; stock LED boards |
| Laser boom | Touching the dome tip at a point, with no fixing and no wire path | Carried on a clear acrylic fin bolted to a bracket on the ballast plate's nose (Figures 20 and 22) | The camera sees the fin edge on; the ring is still measured to within 1 % of diameter |
| Laser head | A bare cone mirror with nothing holding it | A clear window tube and an end cap hold the mirror (Figure 25) | The ring leaves through the window, still 300 mm ahead |
| Ballast plate | 230 x 80 mm, no fixing, a bent 14 mm lip | 255 x 88 mm, square nose, tapped for the side plates, fin bracket and eye bolt (Figure 8) | It is now the crawler's base, tied to the hull by the side plates |
| Tether | No anchor for the strength member; gland in the way of the gearboxes | An eye bolt in the ballast plate takes the pull; a penetrator 77 mm up seals the cable (Figure 9) | Recovery pulls go to steel, not to a seal |
| Reel | Tubes clashing with the flanges; no bearings; a counter floating in the air | Plate side frames on spacer tubes, bearings, a hollow axle, a drum clamped between flanges, a brake, a slip ring anchor and a counter bar (Figures 26 to 35) | Every part cut, drilled or bought, the 320 mm reel size kept |
| Surface box | A battery taller than the case; nothing fixed | A drop-in chassis: base board, four posts and a panel; the case is not drilled (Figures 36 to 38) | The case stays waterproof and the chassis lifts out |
| Mass | 5.8 kg crawler | 6.6 kg crawler; 22.2 kg kit | The added rim, pads, plates and frames; the requirements are still met |

## 3. Making the components

Make and check each component before the assembly step that needs it. The crawler comes first (3.1 to 3.13), then the reel (3.14 to 3.19) and the surface box (3.20 to 3.22). On the reel, the left frame is the crank side and the right frame the slip ring side.

### 3.1 Hull body

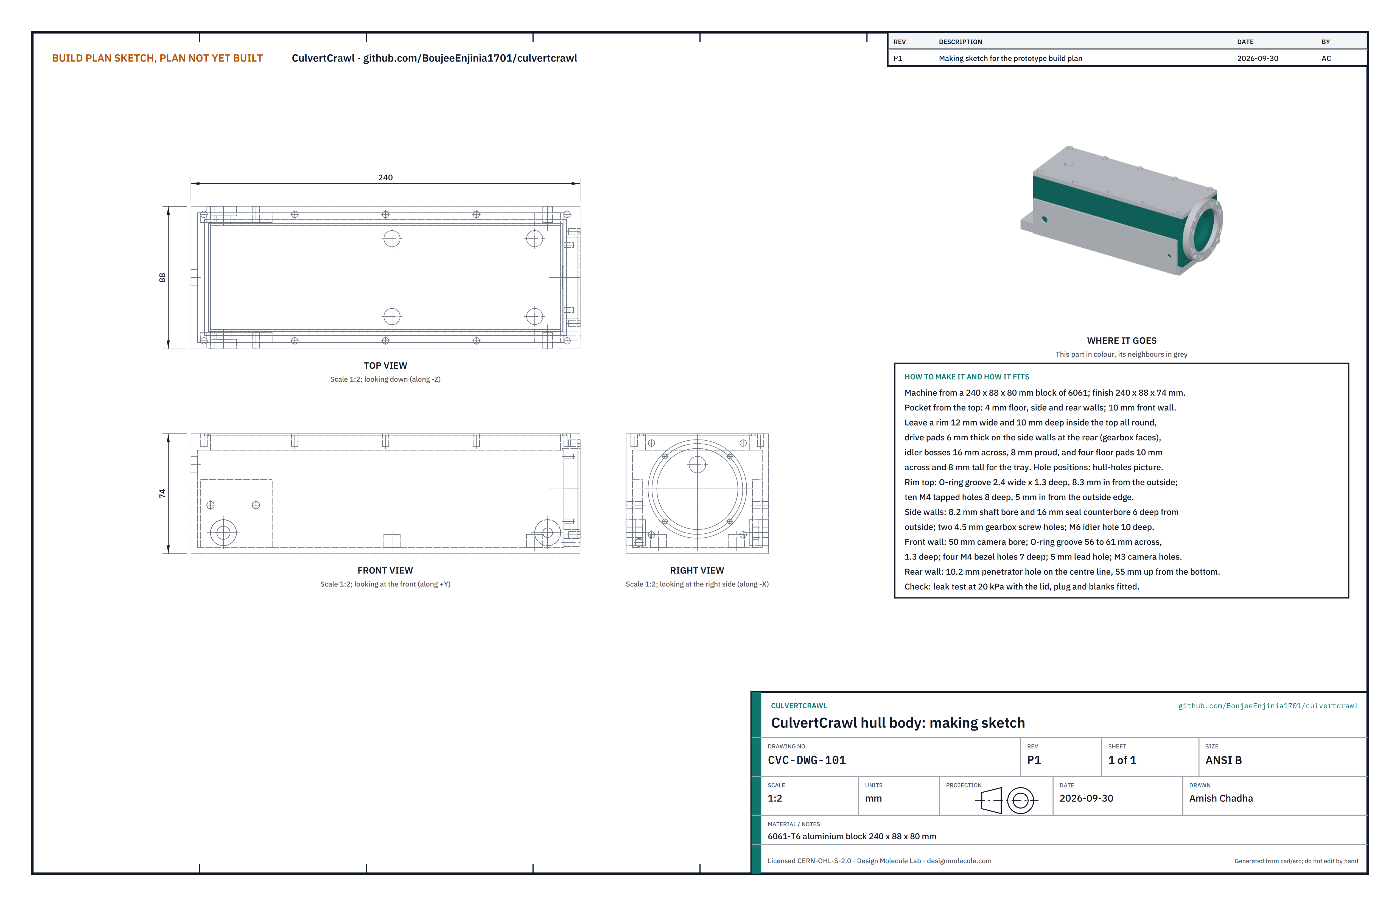
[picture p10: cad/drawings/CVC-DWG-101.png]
Figure 3. Making sketch of the hull body


*Figure 3. Hull body making sketch (CVC-DWG-101).*

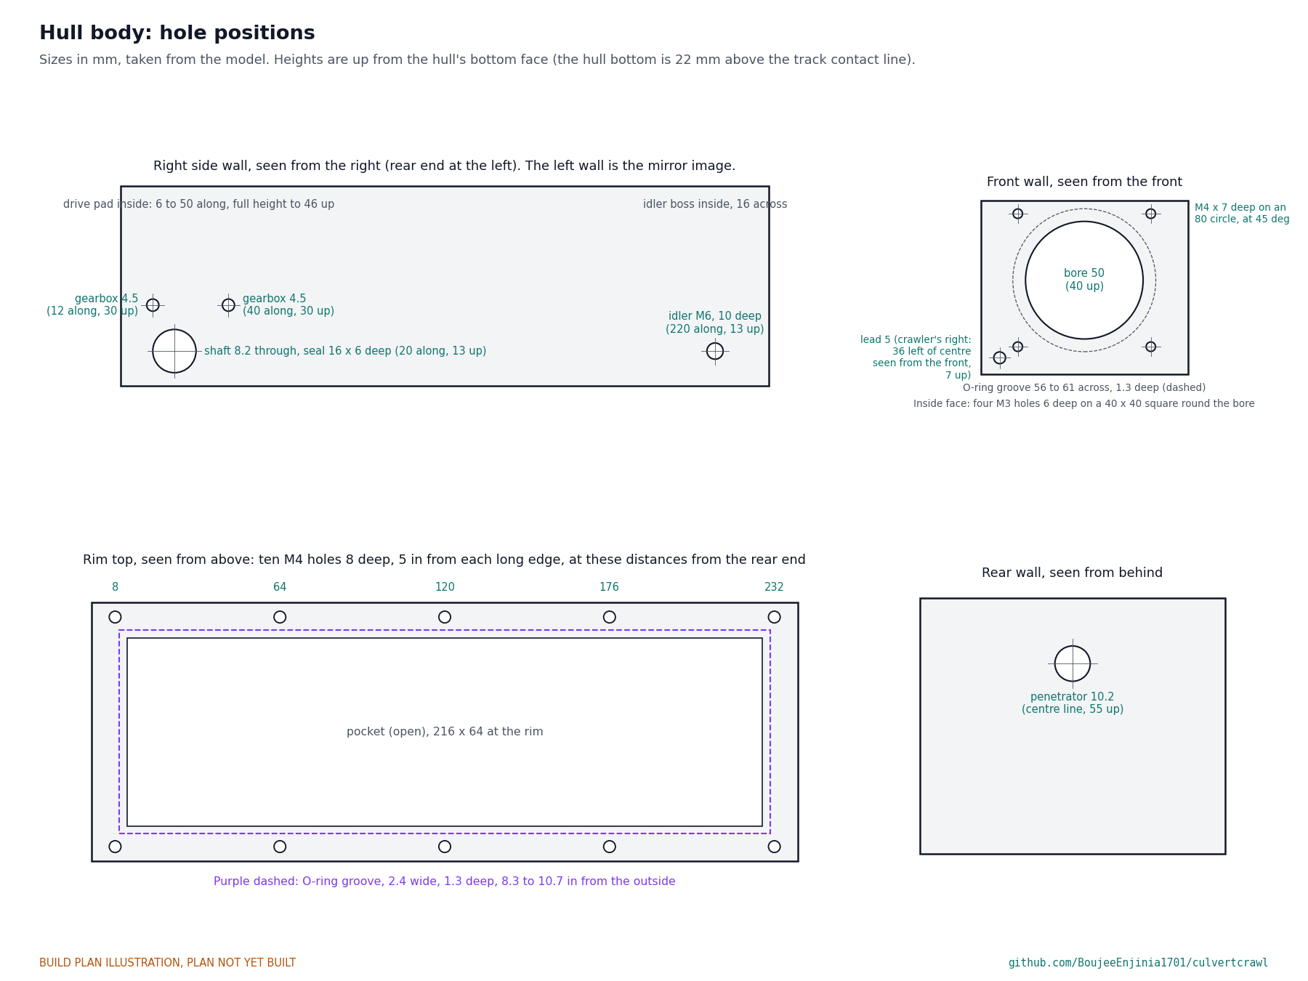
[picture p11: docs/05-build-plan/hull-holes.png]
Figure 4. Hole positions on the hull walls and rim


*Figure 4. Every hole in the hull walls and rim, from the model. Heights on this figure are up from the hull's bottom face.*

**What it is and what it is made from.** The sealed box that holds the motors, the electronics and the camera. 6061-T6 aluminium, machined from a 240 x 88 x 80 mm block; finished 240 x 88 x 74 mm and about 0.92 kg.

**How to make it.**

1. Face the block to 240 x 88 x 74 mm. This is a job for a CNC mill or a machine shop; the drawing and Figure 4 are what to send.
2. Pocket it from the top, leaving a 4 mm floor and 4 mm side and rear walls, and a 10 mm front wall.
3. Leave these inside the pocket, in one setup: a rim 12 mm wide and 10 mm deep round the top; on each side wall a drive pad 6 mm thick from 6 to 50 mm along from the rear end, up to 46 mm above the bottom; on each side wall an idler boss 16 mm across and 8 mm proud at 220 mm along, 13 mm up; and four floor pads 10 mm across and 8 mm tall, 24 mm each side of the centre line, at 124 and 212 mm from the rear end.
4. Rim top: cut the O-ring groove 2.4 mm wide and 1.3 mm deep, 8.3 mm in from the outside edge all round; drill and tap ten M4 holes 8 mm deep, 5 mm in from each long edge, at 8, 64, 120, 176 and 232 mm from the rear end.
5. Side walls, from outside: an 8.2 mm shaft hole through the wall and pad at 20 mm along and 13 mm up, with a 16 mm counterbore 6 mm deep for the lip seal; two 4.5 mm gearbox screw holes through wall and pad at 12 and 40 mm along, 30 mm up, each with a shallow counterbore for a small O-ring; an M6 tapped hole 10 mm deep into the idler boss.
6. Front wall: a 50 mm bore centred 40 mm up; an O-ring groove 56 to 61 mm across and 1.3 mm deep round it; four M4 holes 7 mm deep on an 80 mm circle at 45 degrees; a 5 mm hole for the potted lead 36 mm to the right of the centre line and 7 mm up; four M3 holes 6 mm deep on the inside face, on a 40 mm square round the bore.
7. Rear wall: a 10.2 mm hole on the centre line, 55 mm up, for the tether penetrator.
8. Floor pads: drill and tap M3, 6 mm deep. Deburr everything; break every outside edge.

**How it fits the parts next to it.** The floor sits flat on the ballast plate; the side plates lie flat on both sides; the lid sits on the rim; the dome and bezel sit on the front wall.

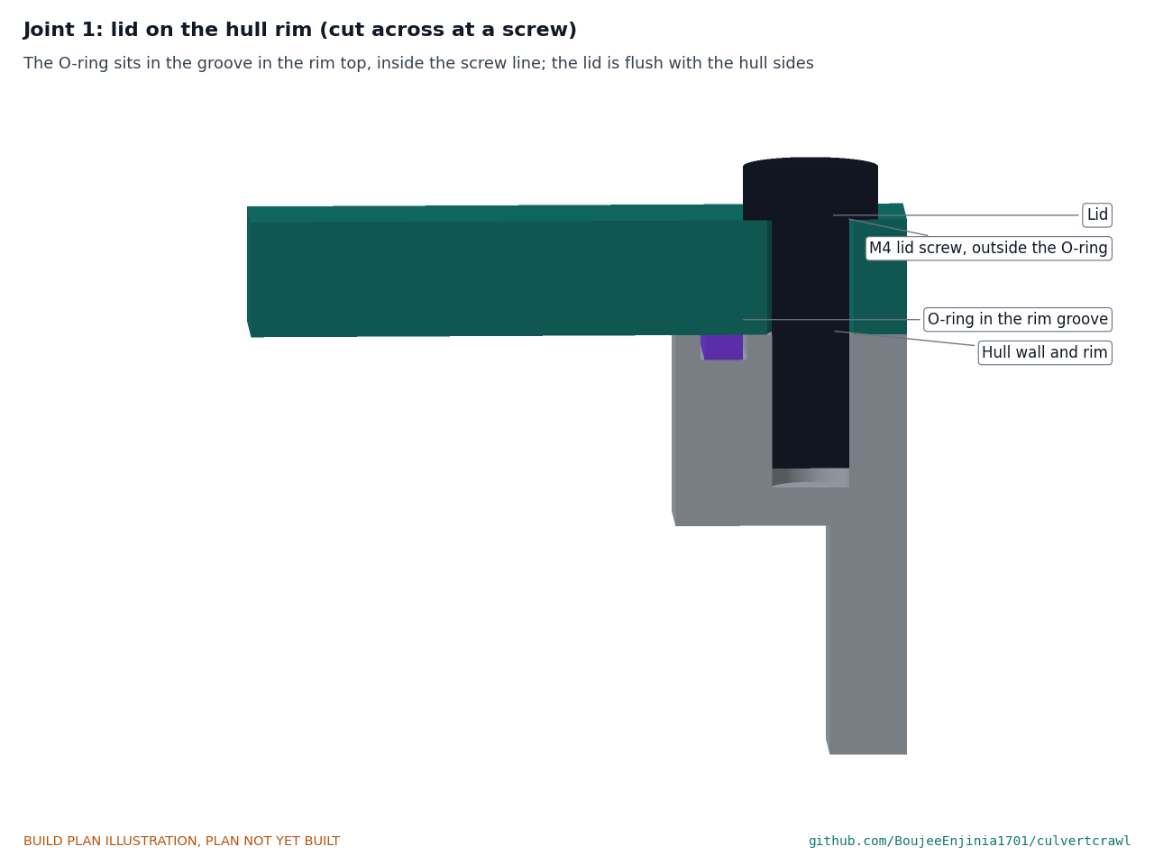
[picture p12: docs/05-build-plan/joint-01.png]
Figure 5. Joint 1: lid on the hull rim


*Figure 5. The O-ring lies in the groove in the rim top, inside the line of lid screws, so no screw hole opens into the sealed space.*

**Check before moving on.** Fit the lid with its O-ring, the test plug, the penetrator with a short cable stub and blanking plugs in the shaft and lead holes, and hold 20 kPa of air for 10 minutes with less than 1 kPa drop.

### 3.2 Hull lid

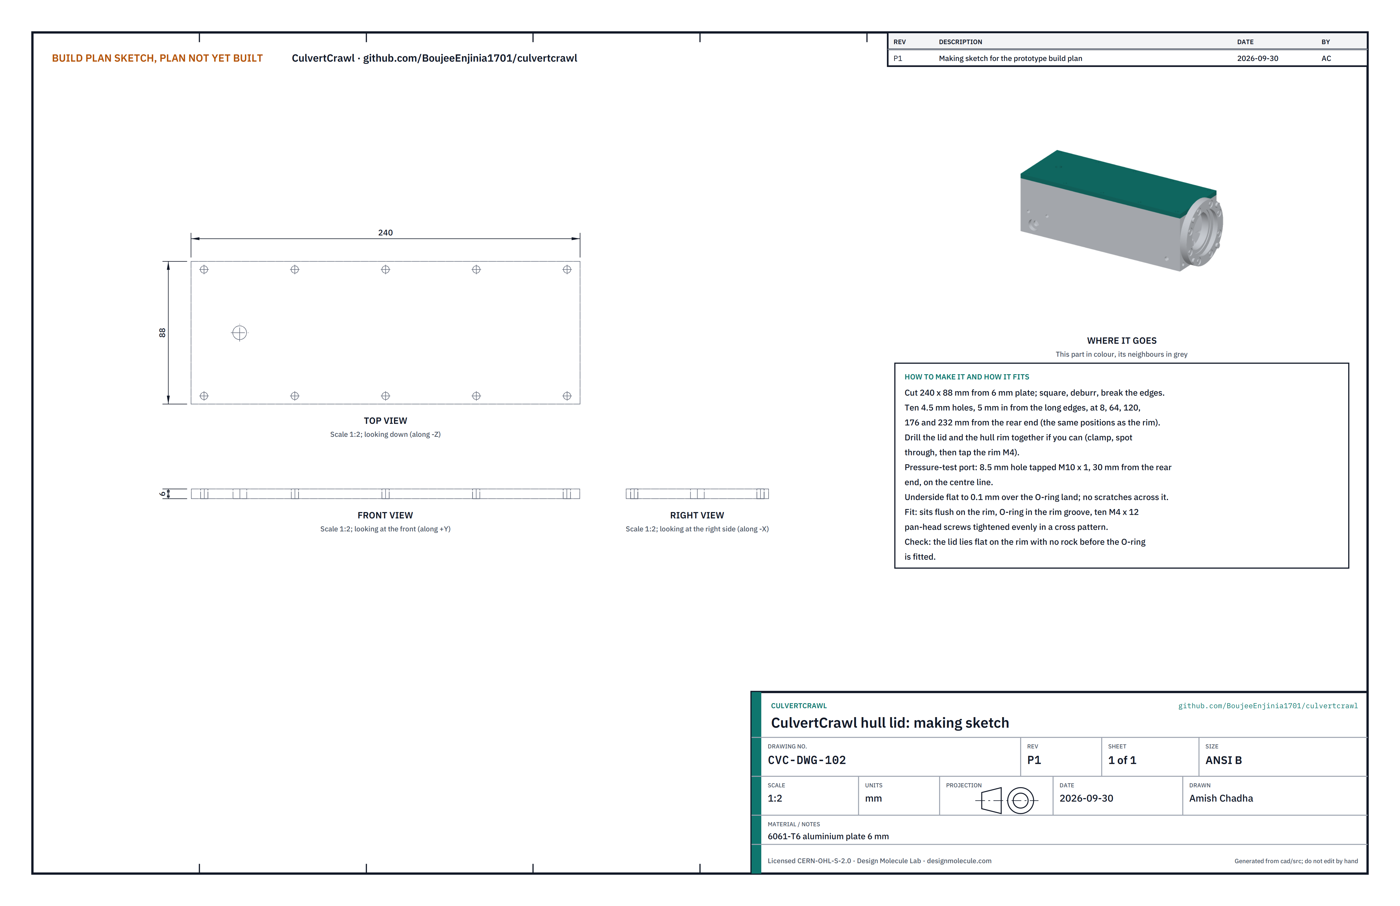
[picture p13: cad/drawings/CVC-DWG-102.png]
Figure 6. Making sketch of the hull lid


*Figure 6. Hull lid making sketch (CVC-DWG-102).*

**What it is and what it is made from.** The flat top of the hull. 6061-T6 aluminium plate 6 mm, 240 x 88 mm.

**How to make it.**

1. Cut 240 x 88 mm, square it and break the edges.
2. Drill ten 4.5 mm holes 5 mm in from the long edges, at 8, 64, 120, 176 and 232 mm from the rear end. If you can, clamp the lid on the hull and spot through before the rim is tapped.
3. Drill 8.5 mm and tap M10 x 1 on the centre line, 30 mm from the rear end, for the pressure-test plug.
4. Keep the underside flat to 0.1 mm over the O-ring land; no scratches across it.

**How it fits the parts next to it.** It sits flush on the rim (Figure 5), held by ten M4 x 12 pan-head screws tightened evenly in a cross pattern.

**Check before moving on.** The lid lies on the rim with no rock before the O-ring goes in.

### 3.3 Ballast skid plate

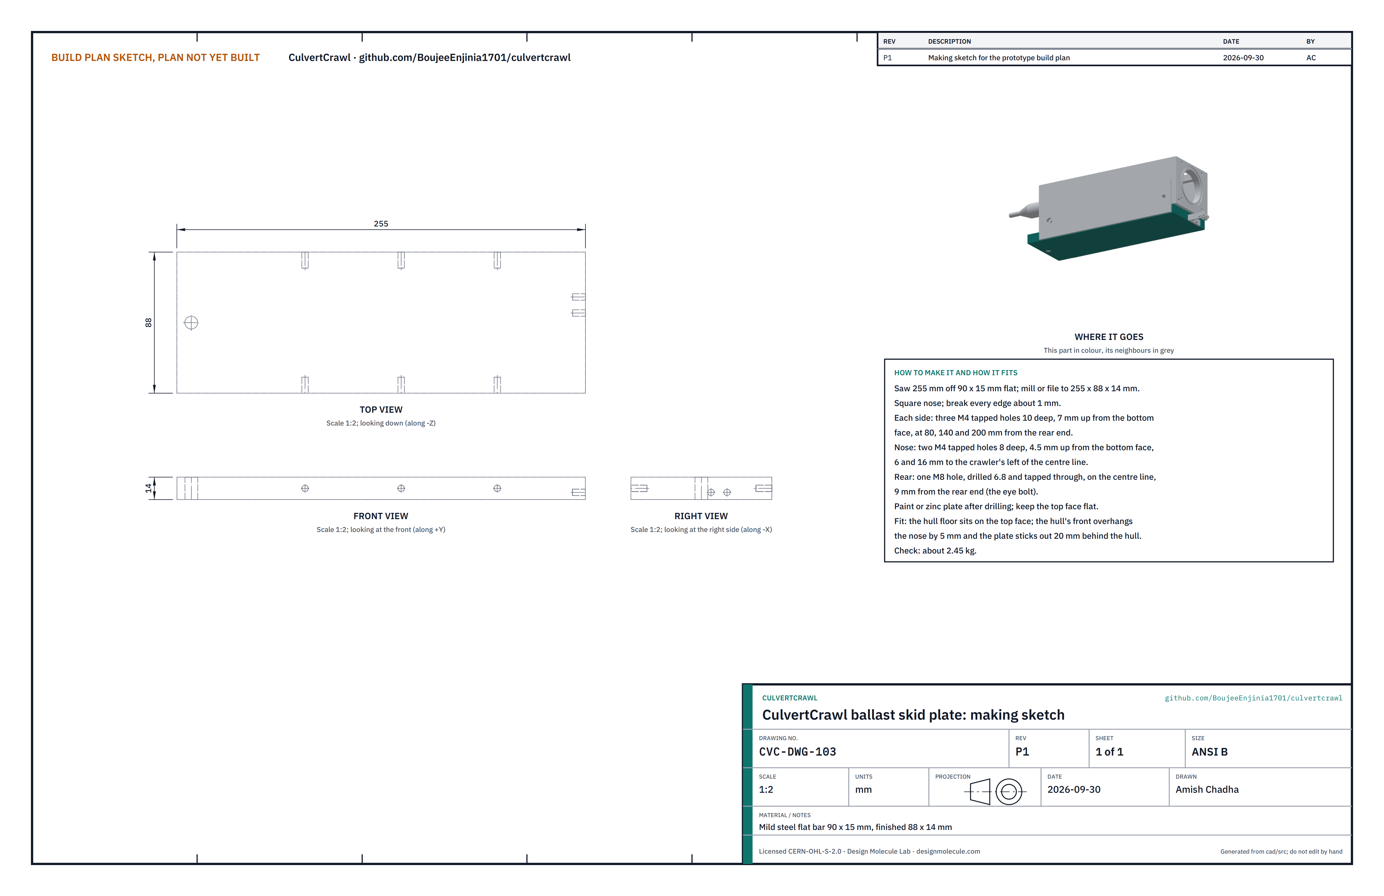
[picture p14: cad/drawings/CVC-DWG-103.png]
Figure 7. Making sketch of the ballast skid plate


*Figure 7. Ballast plate making sketch (CVC-DWG-103).*

**What it is and what it is made from.** The steel plate the hull sits on. It adds traction, protects the hull and is what the side plates, the fin bracket and the tether's eye bolt fasten to. Mild steel flat bar 90 x 15 mm, finished 255 x 88 x 14 mm, about 2.45 kg.

**How to make it.**

1. Saw 255 mm off the bar; mill or file to 255 x 88 x 14 mm with a square nose. Break every edge about 1 mm.
2. Each side: three M4 holes 10 mm deep, 7 mm up from the bottom face, at 80, 140 and 200 mm from the rear end.
3. Nose: two M4 holes 8 mm deep, 4.5 mm up from the bottom face, 6 and 16 mm left of the centre line.
4. Rear: drill 6.8 mm and tap M8 through, on the centre line, 9 mm from the rear end, for the eye bolt.
5. Paint or zinc plate it after drilling; keep the top face flat.

**How it fits the parts next to it.** The hull sits on its top face with the hull's front 5 mm ahead of the nose; the plate sticks out 20 mm behind the hull for the eye bolt.

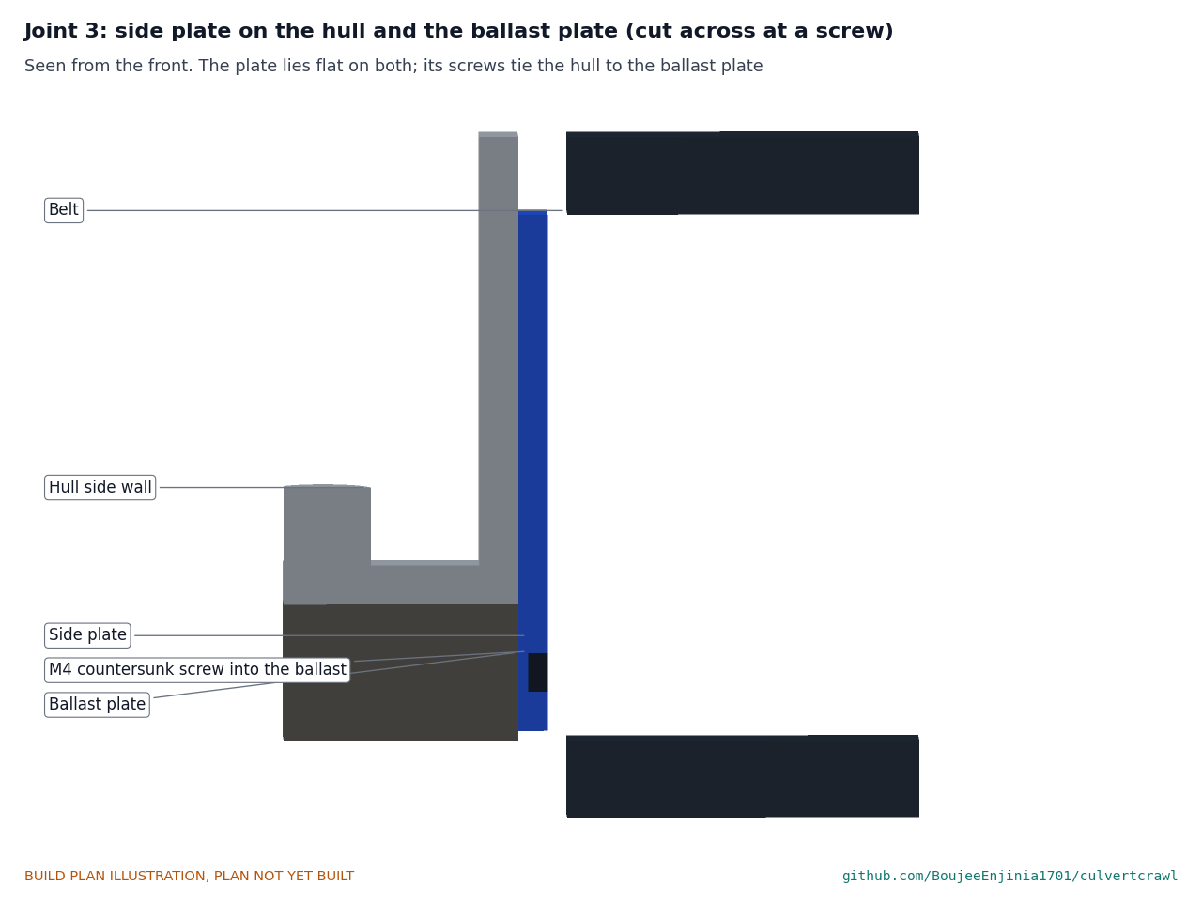
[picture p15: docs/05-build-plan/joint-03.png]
Figure 8. Joint 3: side plate on the hull and the ballast plate


*Figure 8. Each side plate lies flat on the hull side and the ballast side; its countersunk screws into the ballast plate tie the two together. No hole goes through the hull floor.*

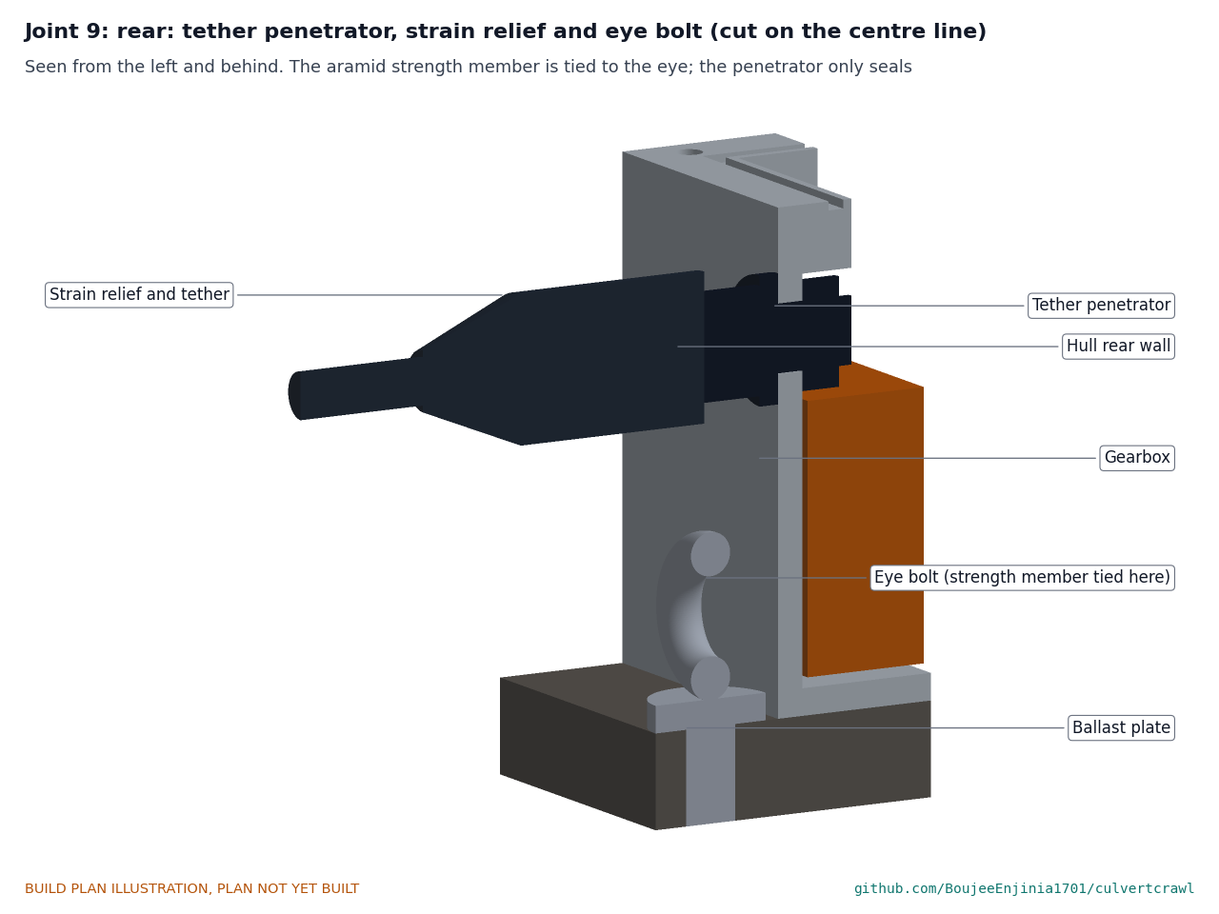
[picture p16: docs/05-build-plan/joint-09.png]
Figure 9. Joint 9: penetrator, strain relief and eye bolt


*Figure 9. The tether's strength member is tied to the eye bolt in the ballast plate; the penetrator in the rear wall only seals the cable.*

**Check before moving on.** About 2.45 kg; the hull sits on it without rocking.

### 3.4 Side plates (make 2, a left and a right)

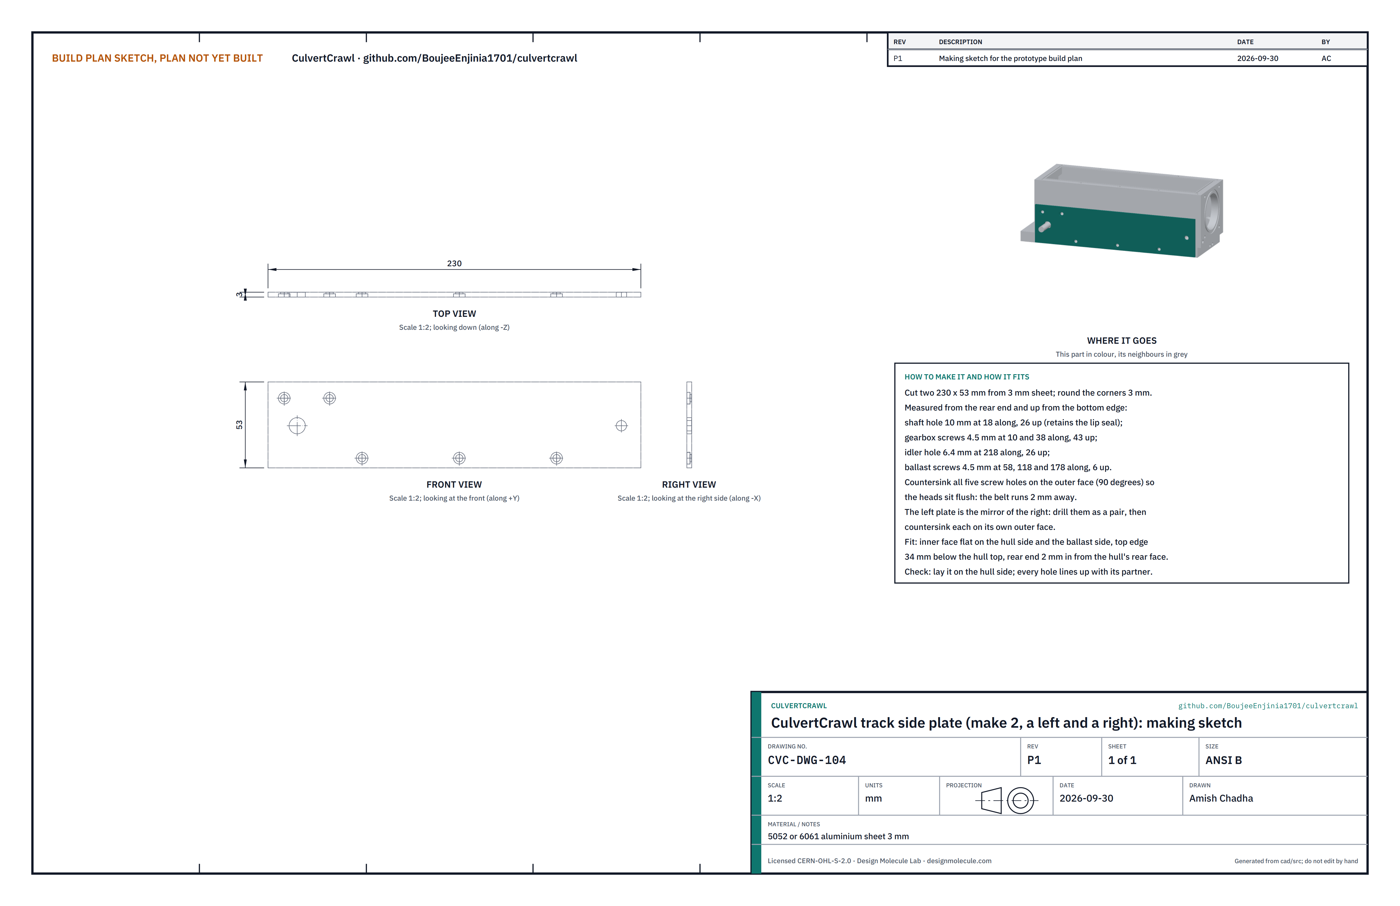
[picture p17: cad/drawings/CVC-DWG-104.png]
Figure 10. Making sketch of the side plate


*Figure 10. Side plate making sketch (CVC-DWG-104), the right plate seen from outside.*

**What it is and what it is made from.** A flat plate on each side between the hull and the track belt. It ties the hull to the ballast plate, holds the shaft seal in and takes the motor screws. 5052 or 6061 aluminium sheet 3 mm, 230 x 53 mm.

**How to make it.**

1. Cut two 230 x 53 mm blanks; round the corners 3 mm.
2. Measured from the rear end and up from the bottom edge: a 10 mm shaft hole at 18 along, 26 up; two 4.5 mm gearbox screw holes at 10 and 38 along, 43 up; a 6.4 mm idler hole at 218 along, 26 up; three 4.5 mm ballast screw holes at 58, 118 and 178 along, 6 up.
3. Drill the two plates clamped together, then countersink the five screw holes on each plate's own outer face (90 degrees) so the heads sit flush: the belt runs 2 mm away.

**How it fits the parts next to it.** The inner face lies flat on the hull side and the ballast side, its rear end 2 mm in from the hull's rear face and its top edge 34 mm below the hull top. It is held by the two gearbox screws (Figure 11), the idler axle bolt (Figure 12) and three M4 countersunk screws into the ballast plate (Figure 8).

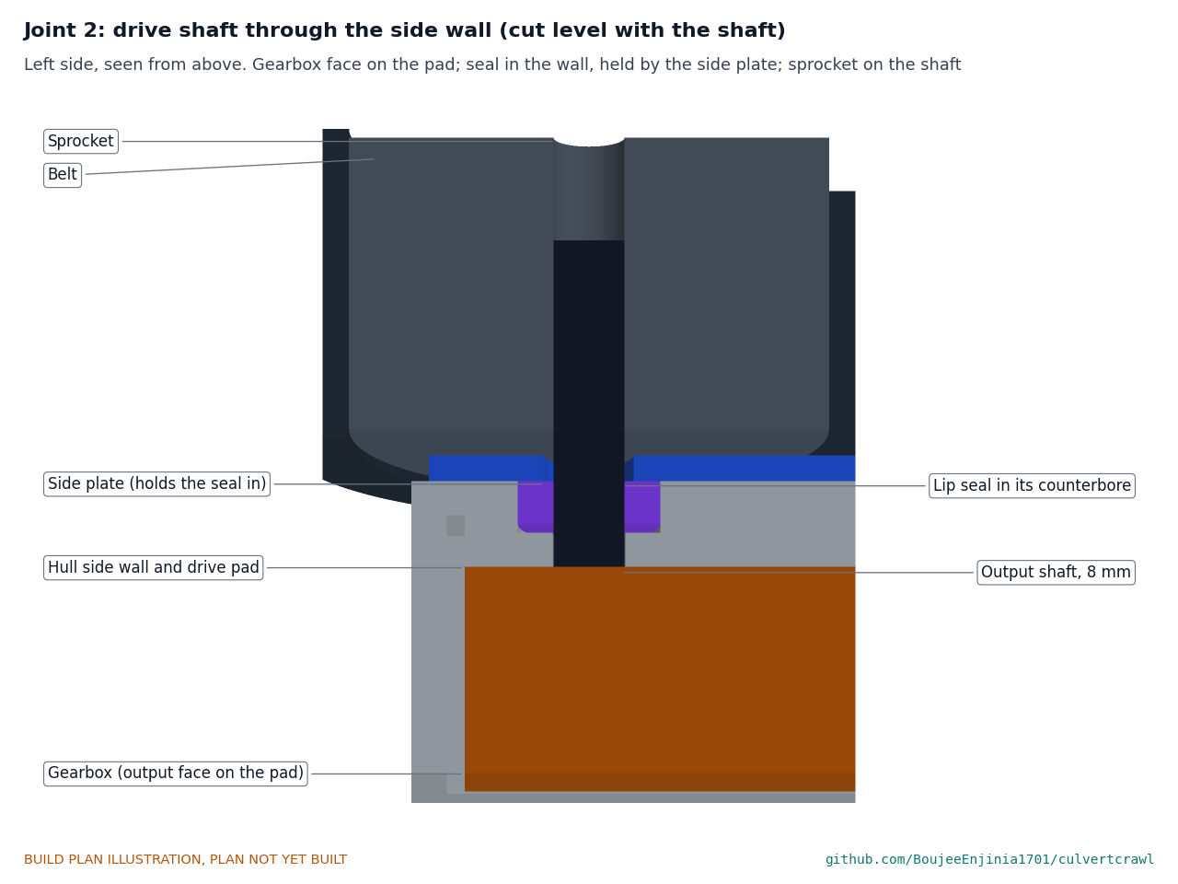
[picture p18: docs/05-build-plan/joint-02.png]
Figure 11. Joint 2: drive shaft through the side wall


*Figure 11. The gearbox's output face sits on the drive pad; the shaft passes the lip seal in the wall counterbore, which the side plate keeps in; the sprocket sits on the shaft.*

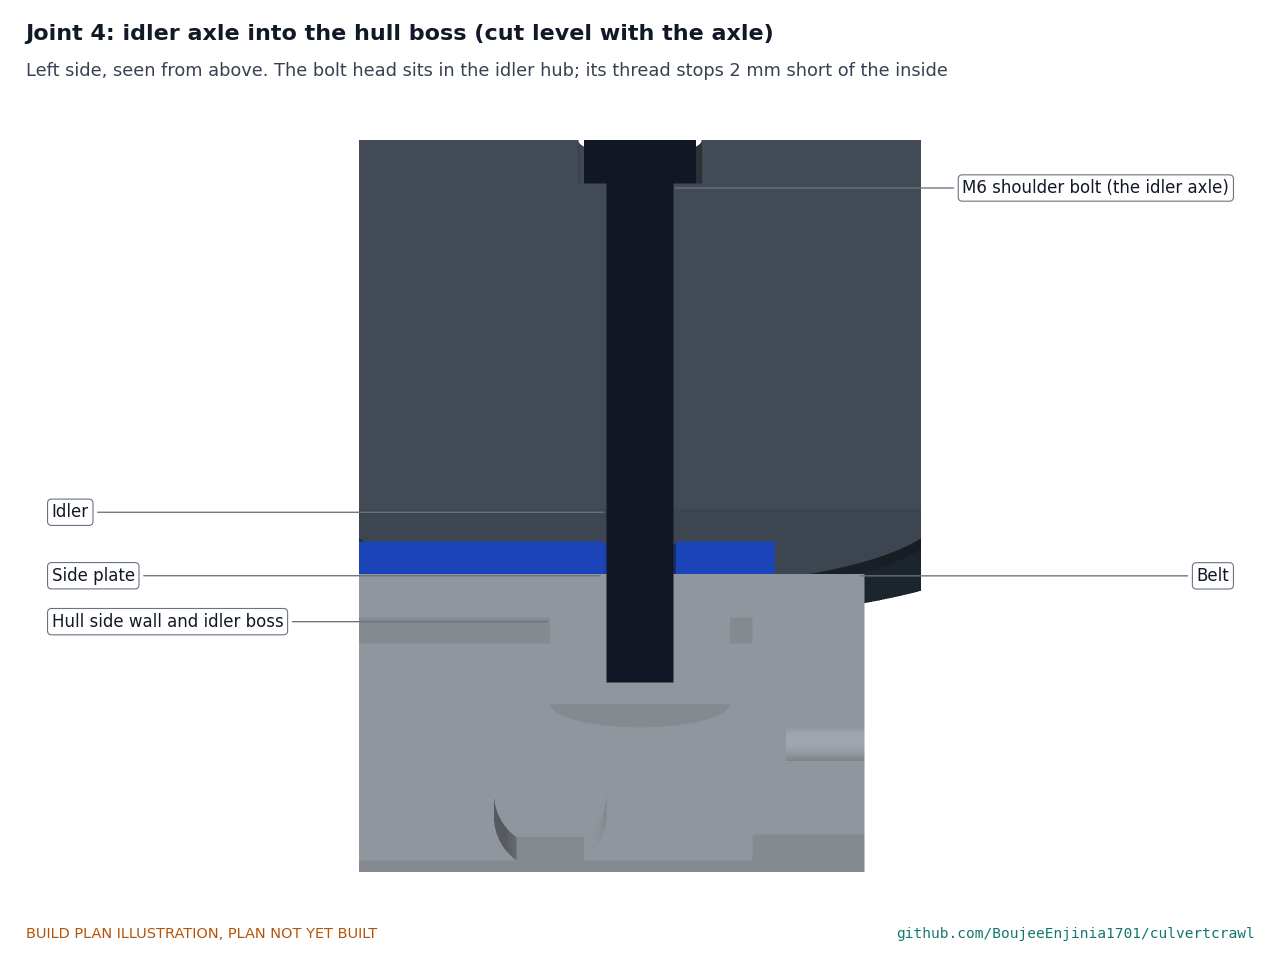
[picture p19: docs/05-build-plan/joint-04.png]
Figure 12. Joint 4: idler axle into the hull boss


*Figure 12. The idler turns on an M6 shoulder bolt whose head sits in the idler hub and whose thread goes into the blind boss in the hull wall.*

**Check before moving on.** Laid on the hull side, every hole lines up with its partner in the hull and the ballast plate.

### 3.5 Bought drive parts: motors, seals, tracks

**What to buy.** Two 12 V self-locking worm gear motors (5840 class) of about 80 rpm, rated 1 N·m or more, with Hall encoders, an 8 mm D output shaft at least 38 mm long and two tapped holes in the output face. Two 8 x 16 x 5 mm double lip shaft seals. A rubber track kit with 36 mm belts on 70 mm sprockets and idlers at 200 mm centres (the kit's own side plates are not used).

**What to do to them.** Bore each sprocket 8 mm D (or buy it so) with an M4 set screw and file a flat on the shaft for it. Ream each idler to run on an M6 shoulder bolt. Grease the seal lips.

**How they fit.** See Figures 11 and 12, and steps 2, 3 and 5.

### 3.6 Electronics tray and deck

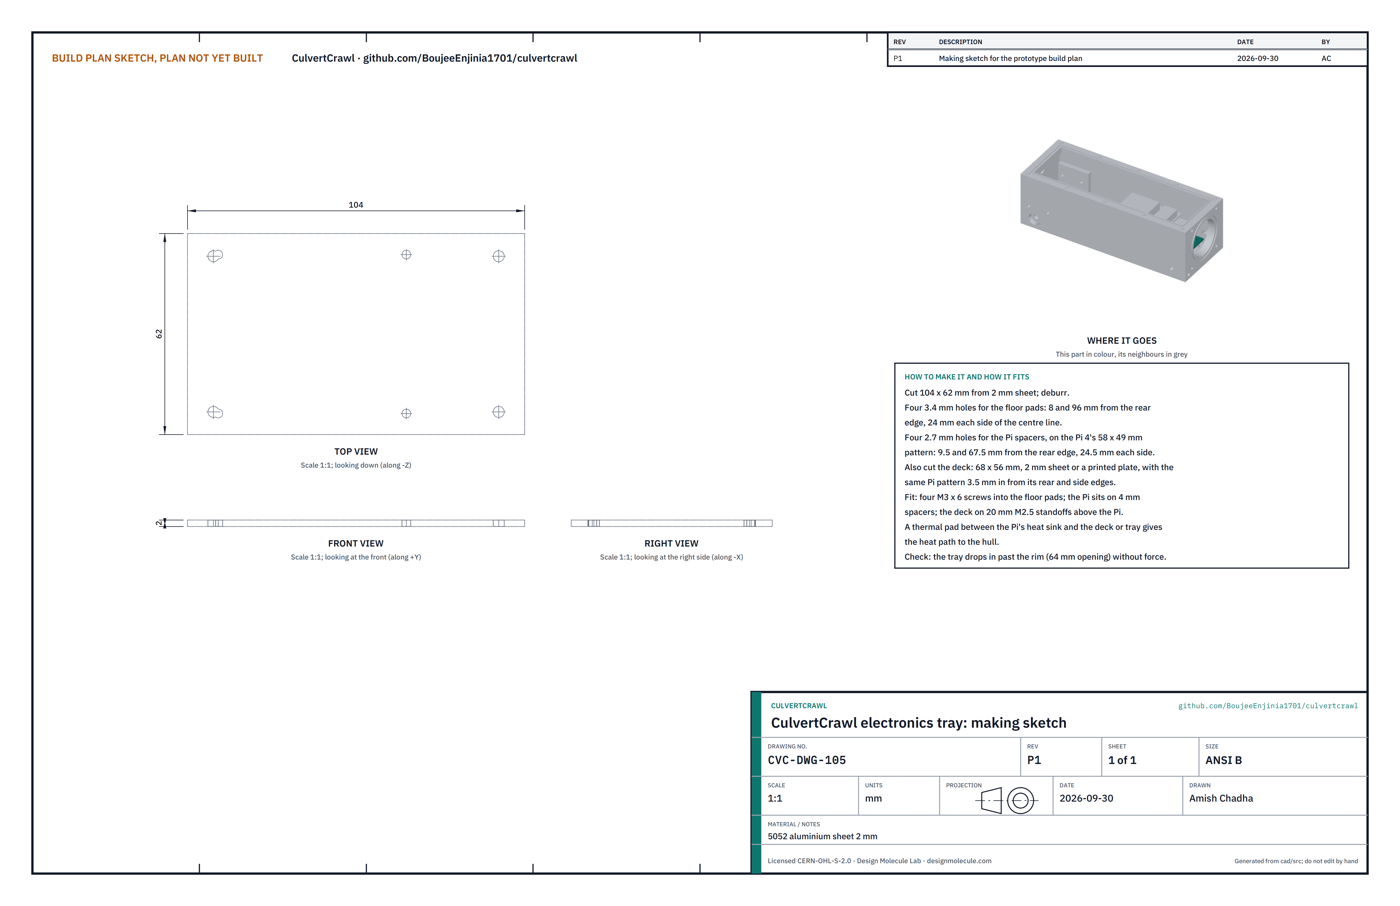
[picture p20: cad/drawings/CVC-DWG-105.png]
Figure 13. Making sketch of the electronics tray


*Figure 13. Electronics tray making sketch (CVC-DWG-105).*

**What it is and what it is made from.** A plate on the floor pads that carries the Raspberry Pi 4, with a deck above the Pi for the motor driver, the converters and the IMU. 5052 aluminium sheet 2 mm.

**How to make it.**

1. Tray: cut 104 x 62 mm. Drill four 3.4 mm holes 8 and 96 mm from the rear edge, 24 mm each side of the centre line (the floor pads), and four 2.7 mm holes on the Pi's 58 x 49 mm pattern, 9.5 and 67.5 mm from the rear edge, 24.5 mm each side.
2. Deck: cut 68 x 56 mm (sheet or a printed plate) with the same Pi pattern 3.5 mm in from its rear and side edges. Lay out the driver, converters and IMU on it and drill their mounting holes through the modules.

**How it fits the parts next to it.** Four M3 x 6 screws hold the tray to the floor pads. The Pi sits on four 4 mm spacers; the deck on four 20 mm M2.5 standoffs above it. A thermal pad between the Pi's heat sink and the tray carries the heat to the hull.

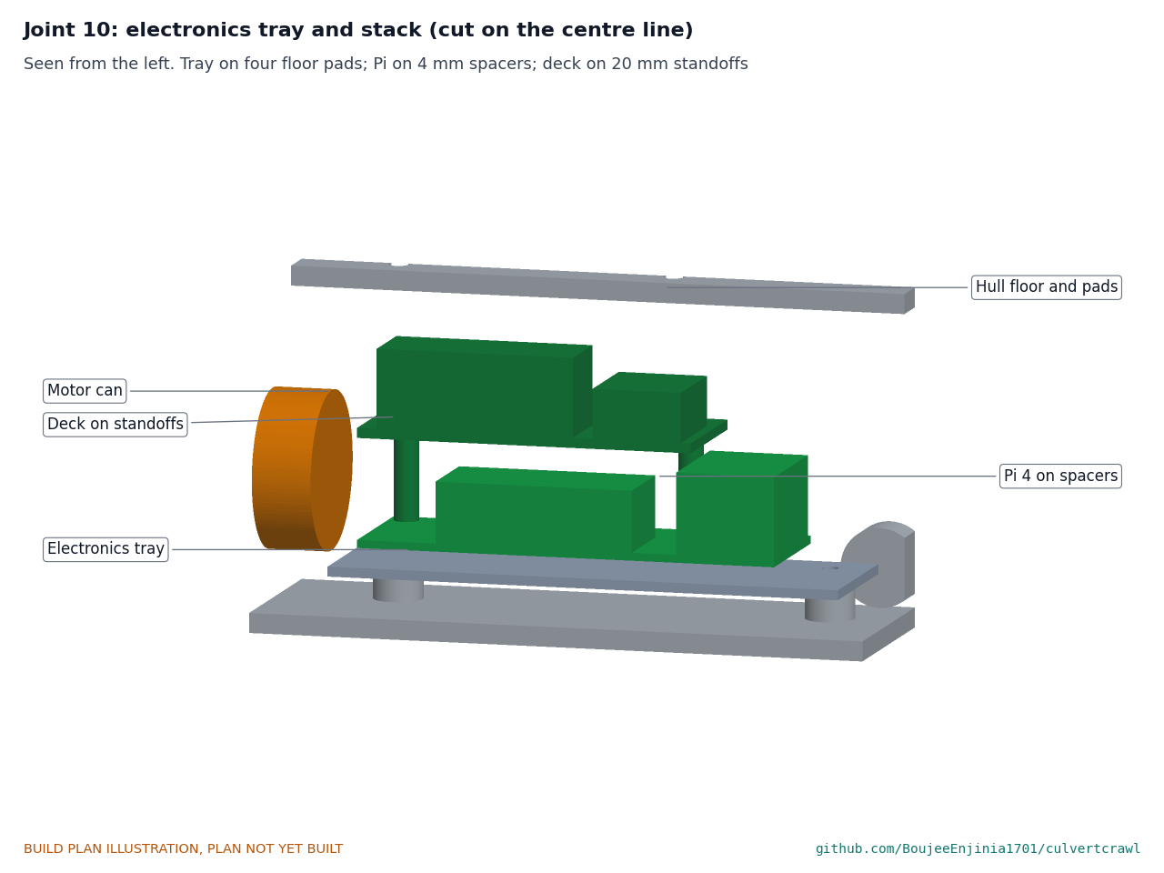
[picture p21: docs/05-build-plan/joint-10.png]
Figure 14. Joint 10: tray and electronics stack


*Figure 14. The tray on its floor pads, the Pi on spacers and the deck on standoffs, 4 mm clear of the motor cans.*

**Check before moving on.** The tray passes the 64 mm opening in the rim without force.

#### 3.6.1 Wiring

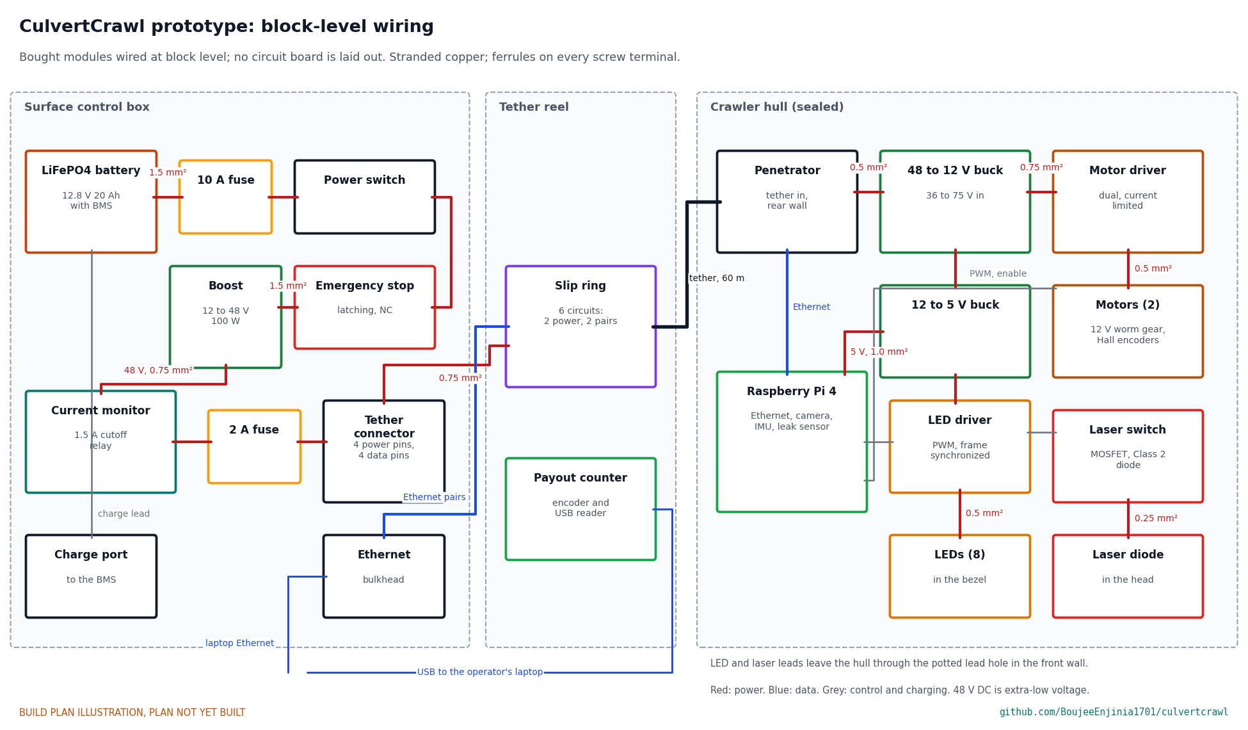
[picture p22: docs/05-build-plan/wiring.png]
Figure 15. Block-level wiring


*Figure 15. Block-level wiring with wire sizes, from the battery to the motors, camera, LEDs and laser.*

Wire with stranded copper and a ferrule on every screw terminal, as Figure 15 shows:

1. Battery, through the 10 A fuse, the power switch and the emergency stop's normally closed contact, to the boost converter input: 1.5 mm² (16 AWG).
2. Boost output (48 V) through the current monitor and the 2 A fuse to the tether connector: 0.75 mm².
3. Tether connector to the slip ring stator: two power wires and two Ethernet pairs. Through the hollow axle, the slip ring rotor to the tether's inner end.
4. In the crawler: tether to the 48 to 12 V buck converter, 0.5 mm²; 12 V to the motor driver, 0.75 mm², and to the 12 to 5 V converter; 5 V to the Pi, 1.0 mm²; driver to each motor, 0.5 mm²; motor encoders to the Pi.
5. Tether Ethernet pairs to an RJ45 plug in the Pi's port; the panel's Ethernet bulkhead to the operator's laptop.
6. Pi to the LED driver (frame-synchronized dimming) and to the laser switch; LED and laser leads, 0.5 and 0.25 mm², out through the potted lead hole in the front wall.
7. Payout counter's USB lead to the laptop; the gamepad to the laptop.

Label every wire. Check every connection end to end before any power goes on (section 6).

### 3.7 Camera mount and camera

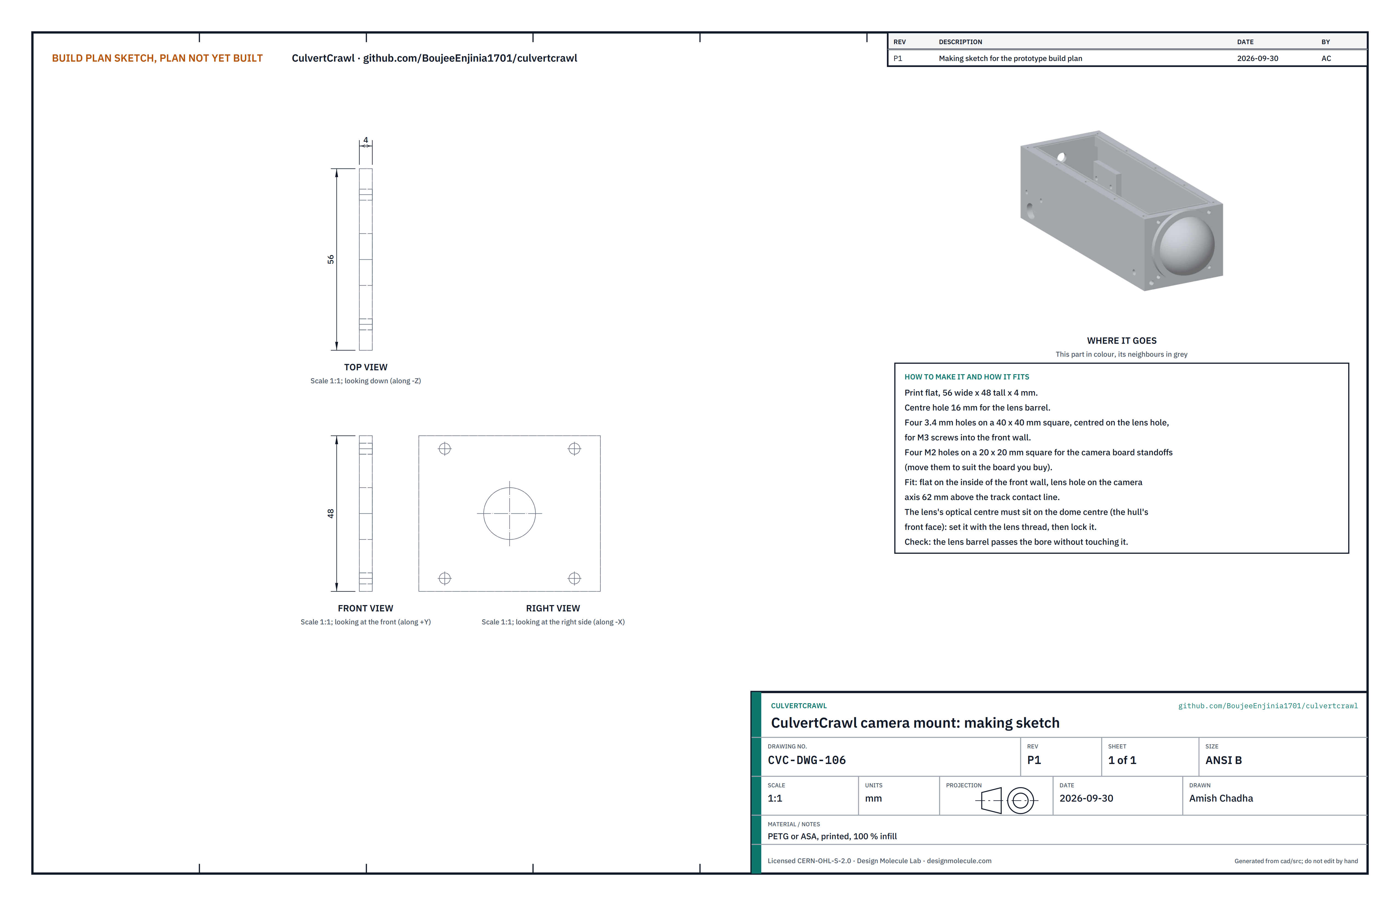
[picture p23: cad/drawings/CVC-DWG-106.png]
Figure 16. Making sketch of the camera mount


*Figure 16. Camera mount making sketch (CVC-DWG-106).*

**What it is and what it is made from.** A printed plate on the inside of the front wall that holds the camera board so the lens looks through the bore. PETG or ASA, printed flat at 100 % infill, 56 x 48 x 4 mm.

**How to make it.**

1. Print with a 16 mm hole at the centre, four 3.4 mm holes on a 40 mm square round it, and four M2 holes on a 20 mm square for the camera board's standoffs (move these to suit the board you buy).
2. Fit the board on M2 standoffs and the fisheye lens in its holder.

**How it fits the parts next to it.** It lies flat on the inside of the front wall on four M3 screws, its centre on the camera axis 62 mm up. Screw the lens in or out until its optical centre is at the hull's front face (the dome centre), then lock the thread (Figure 18).

**Check before moving on.** The lens barrel clears the bore all round.

### 3.8 Front bezel and LEDs

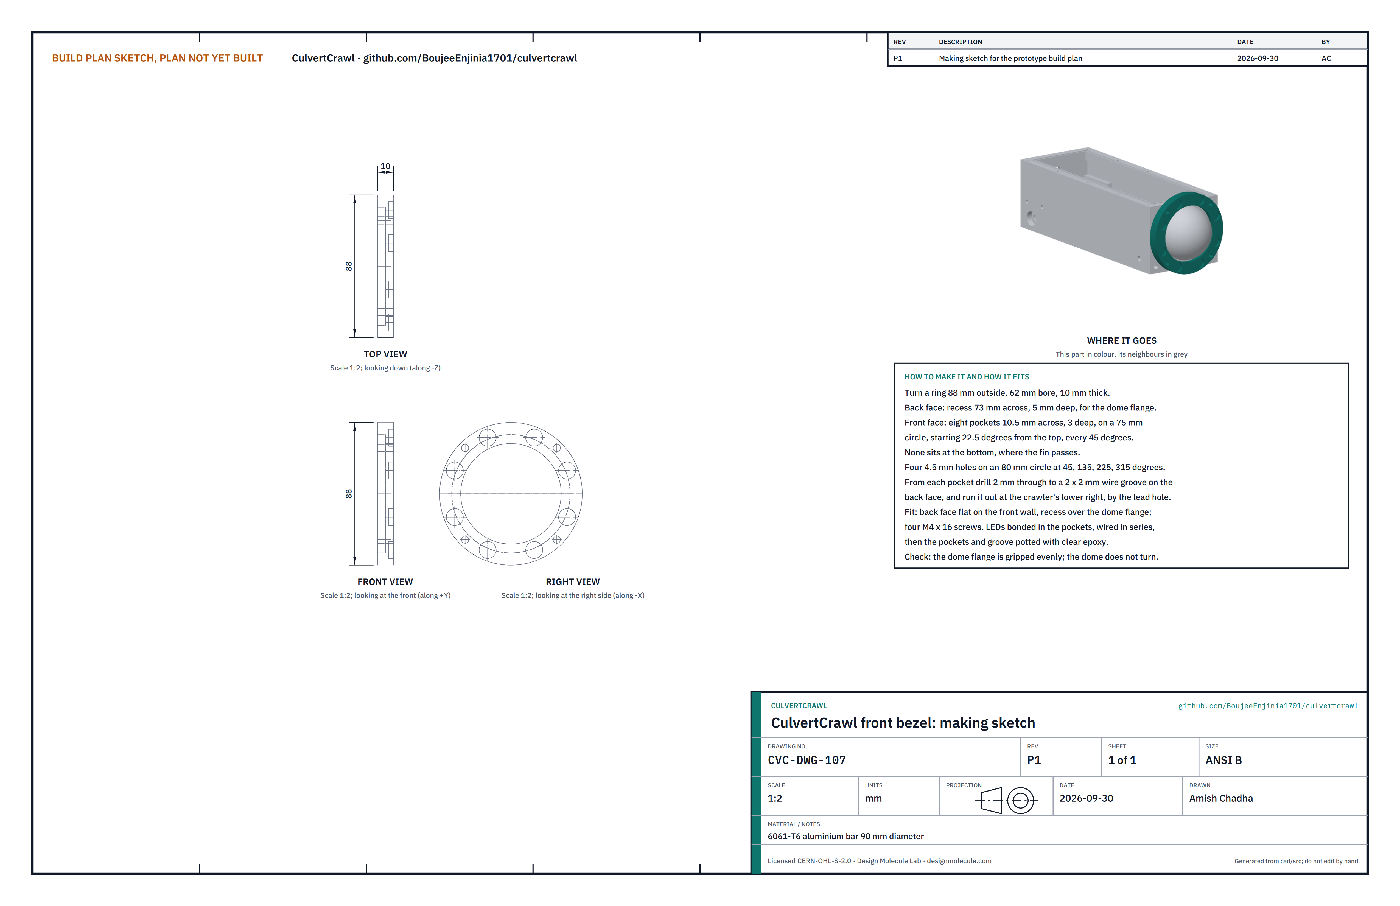
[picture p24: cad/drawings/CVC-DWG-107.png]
Figure 17. Making sketch of the front bezel


*Figure 17. Front bezel making sketch (CVC-DWG-107).*

**What it is and what it is made from.** A ring on the front of the hull that clamps the dome down on its O-ring and carries the eight LEDs. 6061-T6 aluminium bar 90 mm across.

**How to make it.**

1. Turn a ring 88 mm outside, 62 mm bore, 10 mm thick.
2. Back face: a recess 73 mm across and 5 mm deep for the dome flange.
3. Front face: eight pockets 10.5 mm across and 3 mm deep on a 75 mm circle, the first 22.5 degrees from the top and then every 45 degrees. None sits at the bottom, where the fin passes.
4. Four 4.5 mm holes on an 80 mm circle at 45, 135, 225 and 315 degrees.
5. From each pocket drill 2 mm through to a 2 x 2 mm wire groove on the back face, and run the groove out at the lower right, beside the lead hole in the front wall.
6. Bond an LED on its 10 mm board into each pocket with thermal epoxy, wire them in series through the groove, check they light, then pot the pockets and the groove with clear epoxy.

**How it fits the parts next to it.** The back face lies flat on the front wall with the recess over the dome flange; four M4 x 16 screws clamp it.

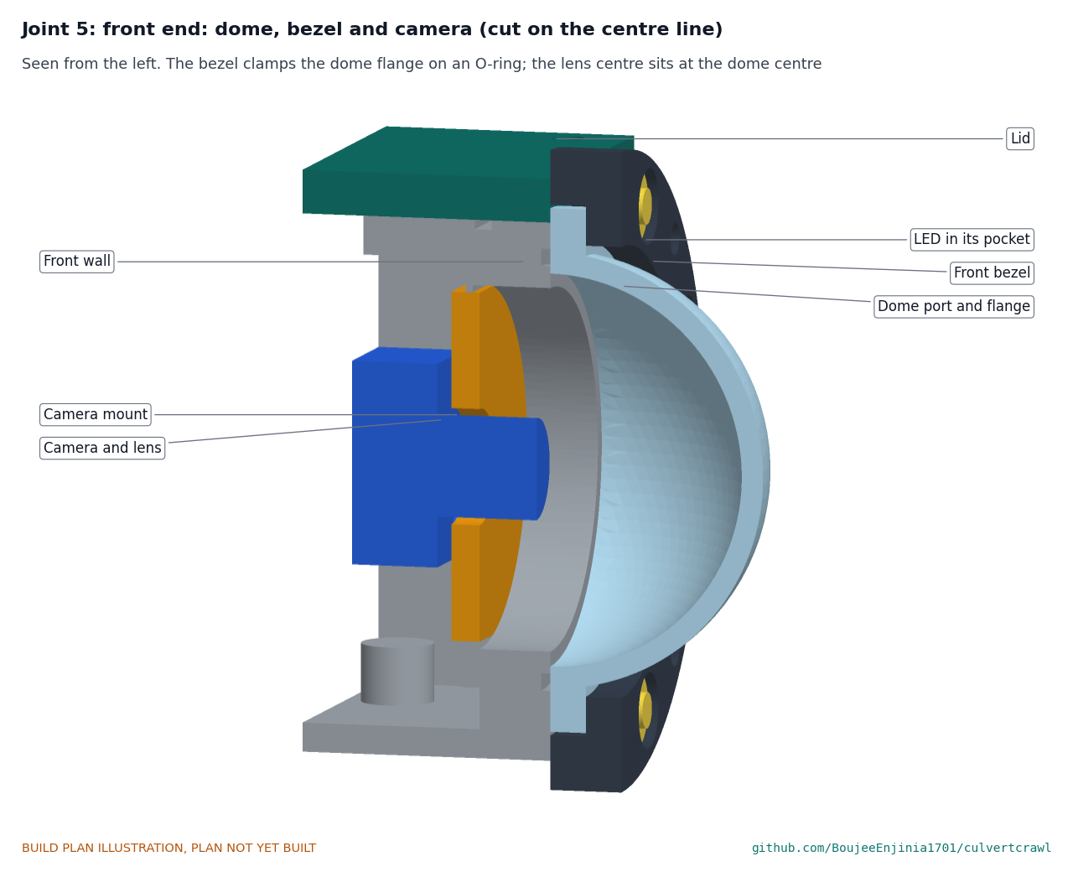
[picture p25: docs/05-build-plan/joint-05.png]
Figure 18. Joint 5: front end


*Figure 18. The bezel clamps the dome flange on the O-ring in the front wall; the camera mount sits on the inside of the wall with the lens centre at the dome centre.*

**Check before moving on.** All eight LEDs light at low current before potting; after fitting, the dome cannot be turned by hand.

### 3.9 Fin bracket

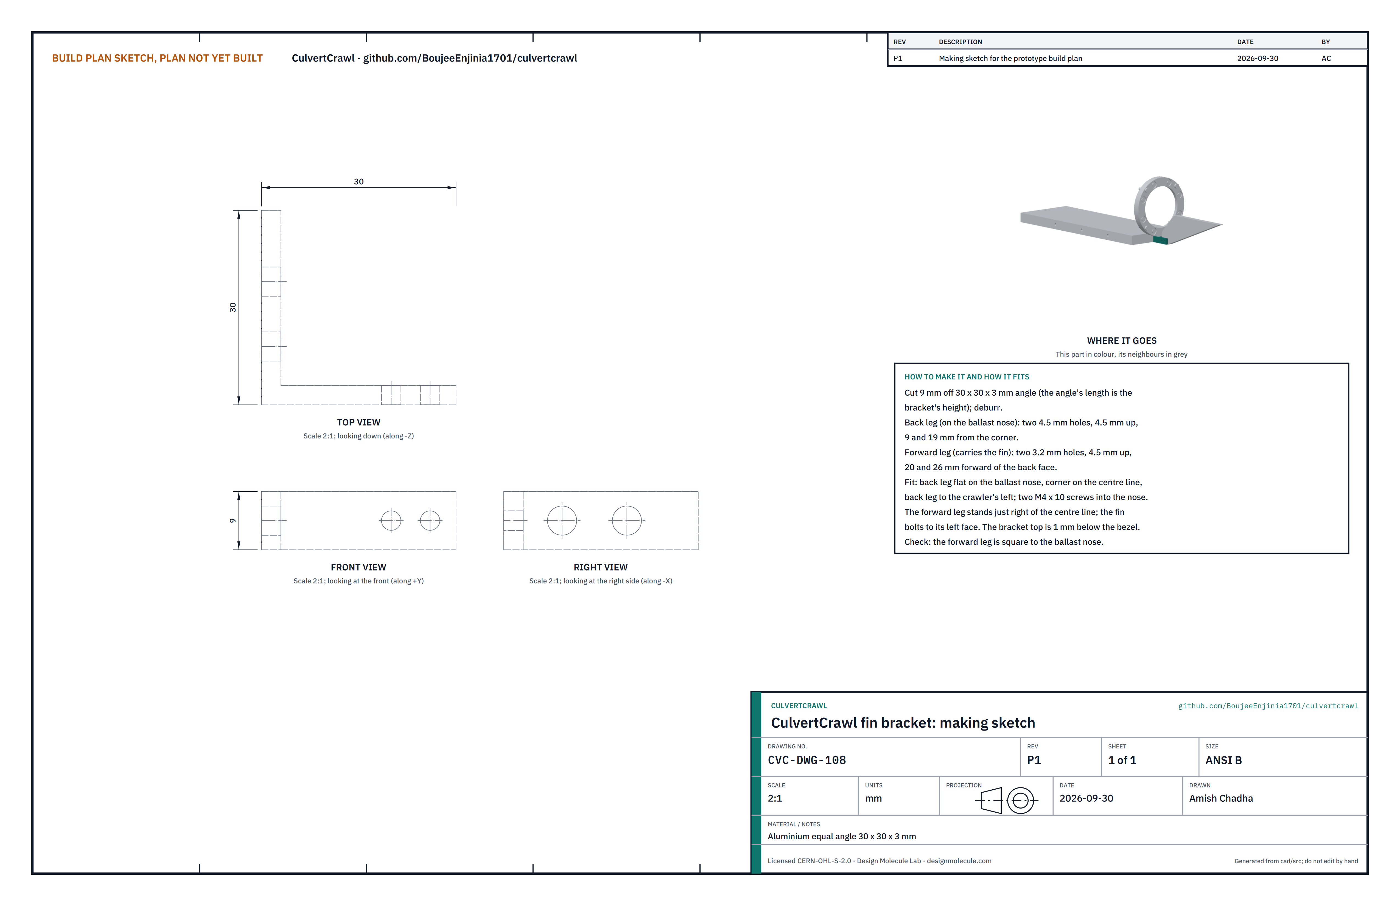
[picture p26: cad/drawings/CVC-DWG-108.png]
Figure 19. Making sketch of the fin bracket


*Figure 19. Fin bracket making sketch (CVC-DWG-108).*

**What it is and what it is made from.** A short angle on the nose of the ballast plate that the boom fin bolts to. Aluminium equal angle 30 x 30 x 3 mm.

**How to make it.**

1. Cut 9 mm off the angle (the angle's length is the bracket's height) and deburr it.
2. Back leg: two 4.5 mm holes 4.5 mm up, 9 and 19 mm from the corner.
3. Forward leg: two 3.2 mm holes 4.5 mm up, 20 and 26 mm forward of the back face.

**How it fits the parts next to it.** The back leg lies flat on the ballast plate's nose, its corner on the centre line and the leg running to the left, on two M4 x 10 screws. The forward leg stands just right of the centre line; the fin bolts to its left face. The bracket's top is 1 mm below the bezel.

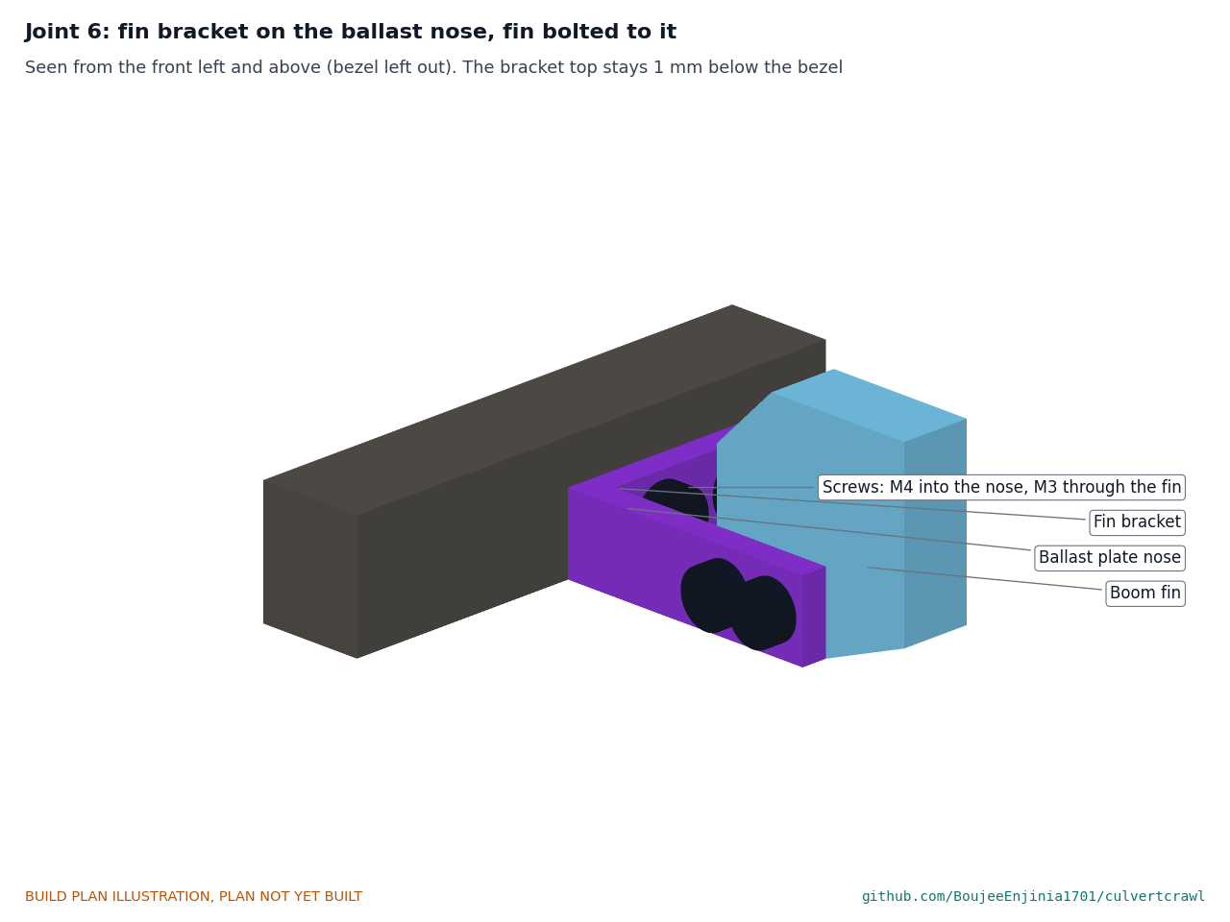
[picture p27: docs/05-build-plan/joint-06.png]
Figure 20. Joint 6: fin bracket and fin


*Figure 20. The bracket on the ballast plate's nose with the fin bolted to it (bezel left out of the picture).*

**Check before moving on.** The forward leg is square to the nose.

### 3.10 Boom fin

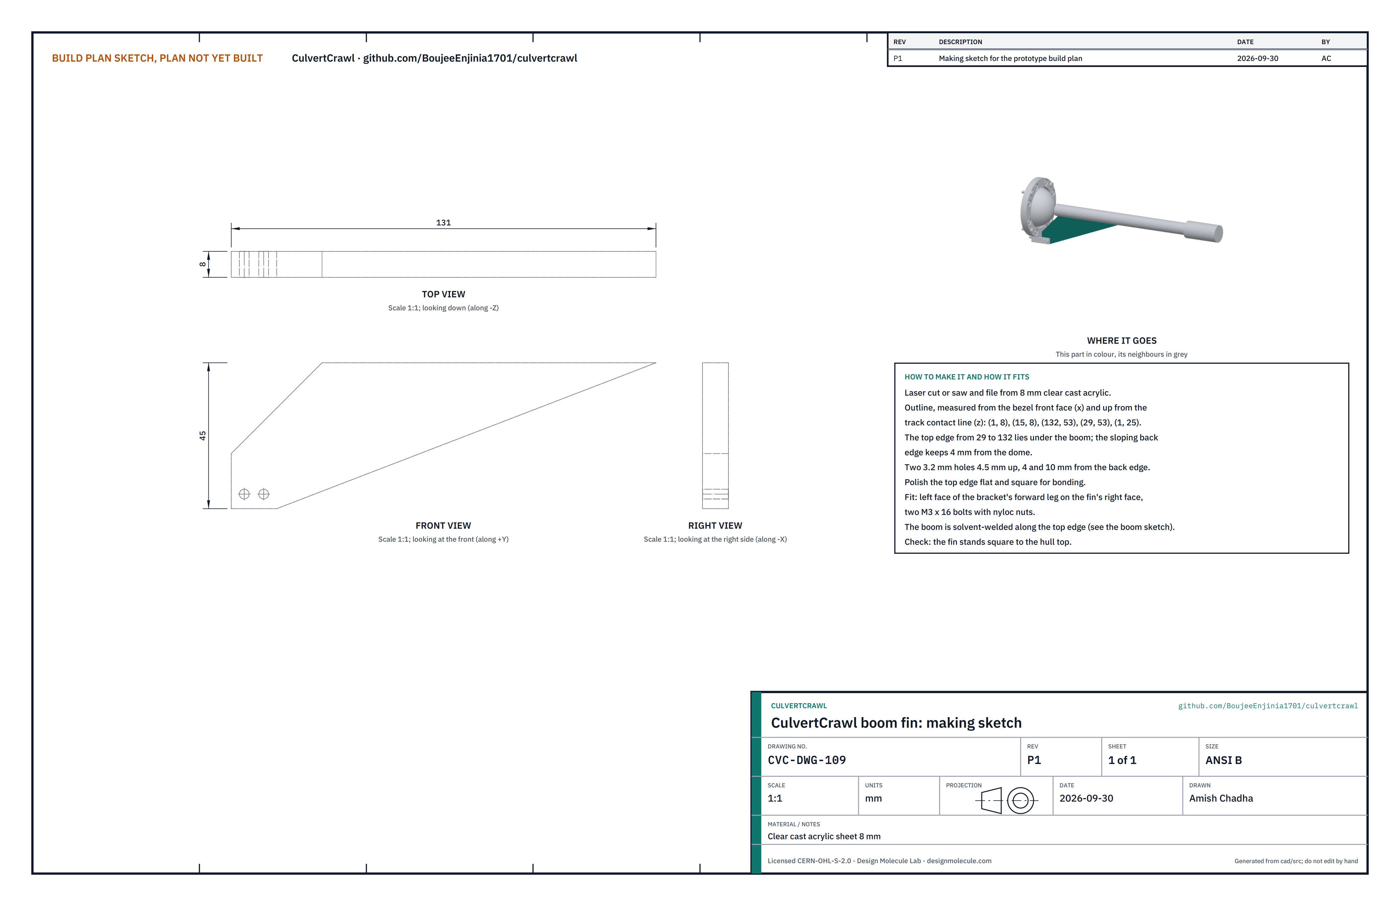
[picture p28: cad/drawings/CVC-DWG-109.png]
Figure 21. Making sketch of the boom fin


*Figure 21. Boom fin making sketch (CVC-DWG-109).*

**What it is and what it is made from.** A clear plate standing on the bracket that carries the laser boom on the camera axis. Clear cast acrylic sheet 8 mm.

**How to make it.**

1. Laser cut it, or saw and file it. Measured forward from the bezel's front face and up from the track contact line, its corners are at (1, 8), (15, 8), (132, 53), (29, 53) and (1, 25).
2. Two 3.2 mm holes 4.5 mm up, 4 and 10 mm from the back edge.
3. Polish the top edge flat and square for bonding.

**How it fits the parts next to it.** Its right face lies on the bracket's forward leg, held by two M3 x 16 bolts with nyloc nuts. The boom is solvent-welded along its top edge. Its sloping back edge stays 4 mm from the dome.

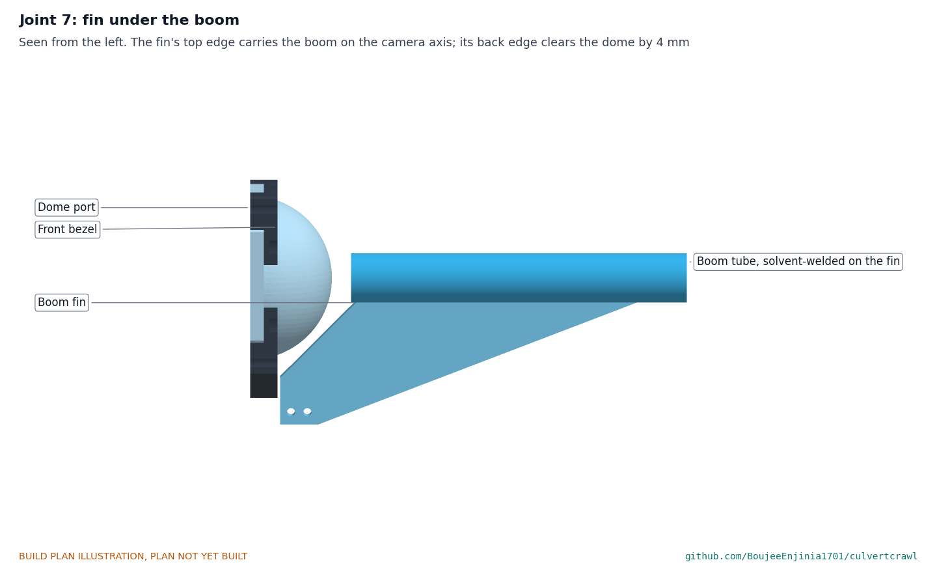
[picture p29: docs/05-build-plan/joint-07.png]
Figure 22. Joint 7: fin under the boom


*Figure 22. The fin's top edge carries the boom on the camera axis. The camera sees the fin edge on, so it hides only a thin strip of the ring at the bottom of the pipe.*

**Check before moving on.** The fin stands square to the hull top.

### 3.11 Boom tube

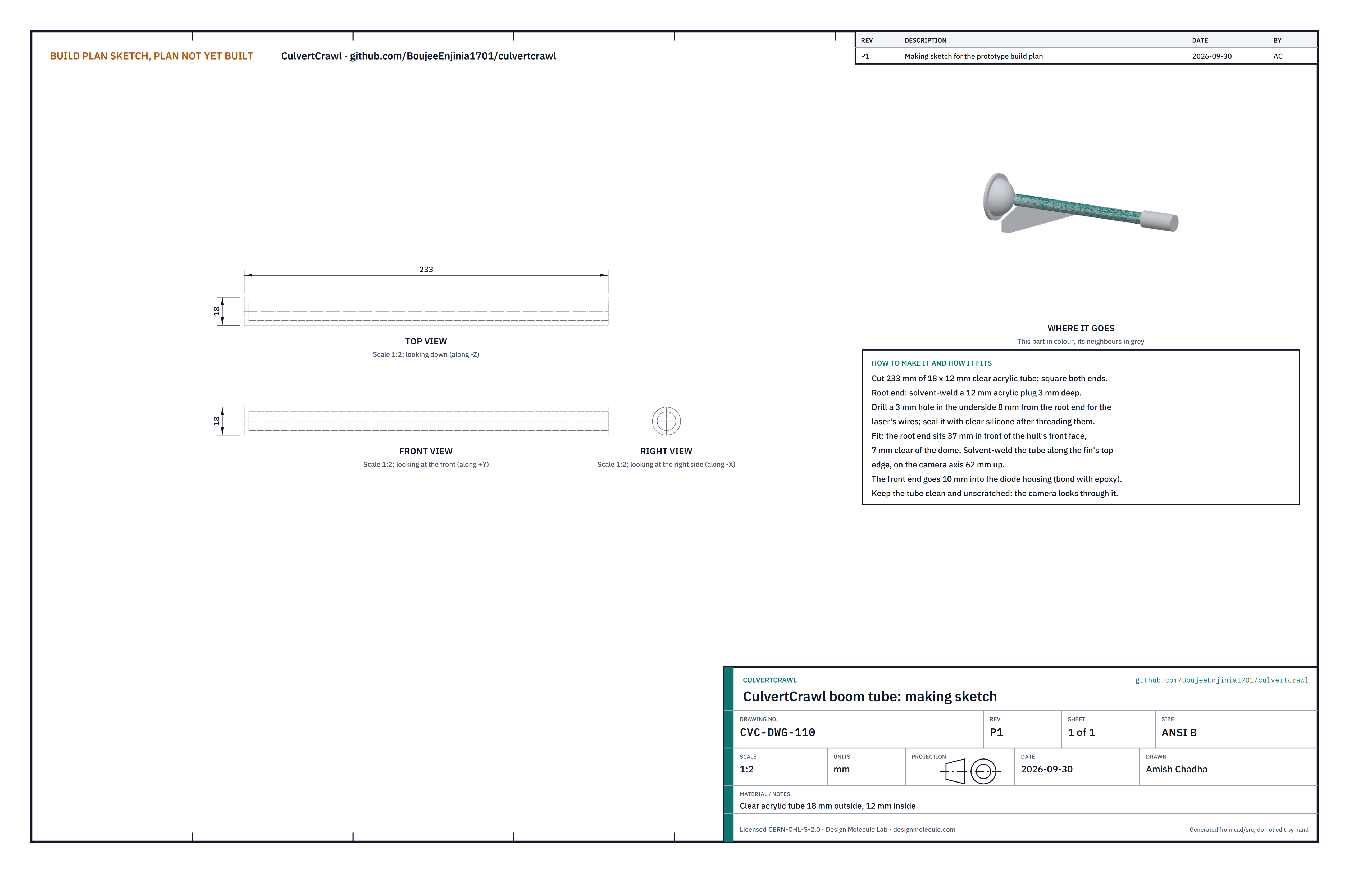
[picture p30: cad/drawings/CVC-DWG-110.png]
Figure 23. Making sketch of the boom tube


*Figure 23. Boom tube making sketch (CVC-DWG-110).*

**What it is and what it is made from.** The clear tube that holds the laser head 300 mm ahead of the camera. Clear acrylic tube 18 mm outside, 12 mm inside, 233 mm long.

**How to make it.**

1. Cut 233 mm and square both ends.
2. Solvent-weld a 12 mm acrylic plug 3 mm into the root end.
3. Drill a 3 mm hole in the underside 8 mm from the root end for the laser's wires.
4. Thread the laser's leads through the tube before the head is bonded on; seal the 3 mm hole with clear silicone afterwards.

**How it fits the parts next to it.** The root end sits 37 mm in front of the hull's front face, 7 mm clear of the dome, and the tube is solvent-welded along the fin's top edge. Its front end goes 10 mm into the diode housing (Figure 25).

**Check before moving on.** The tube is clean and unscratched; the camera looks through it.

### 3.12 Laser head: diode housing, window and end cap

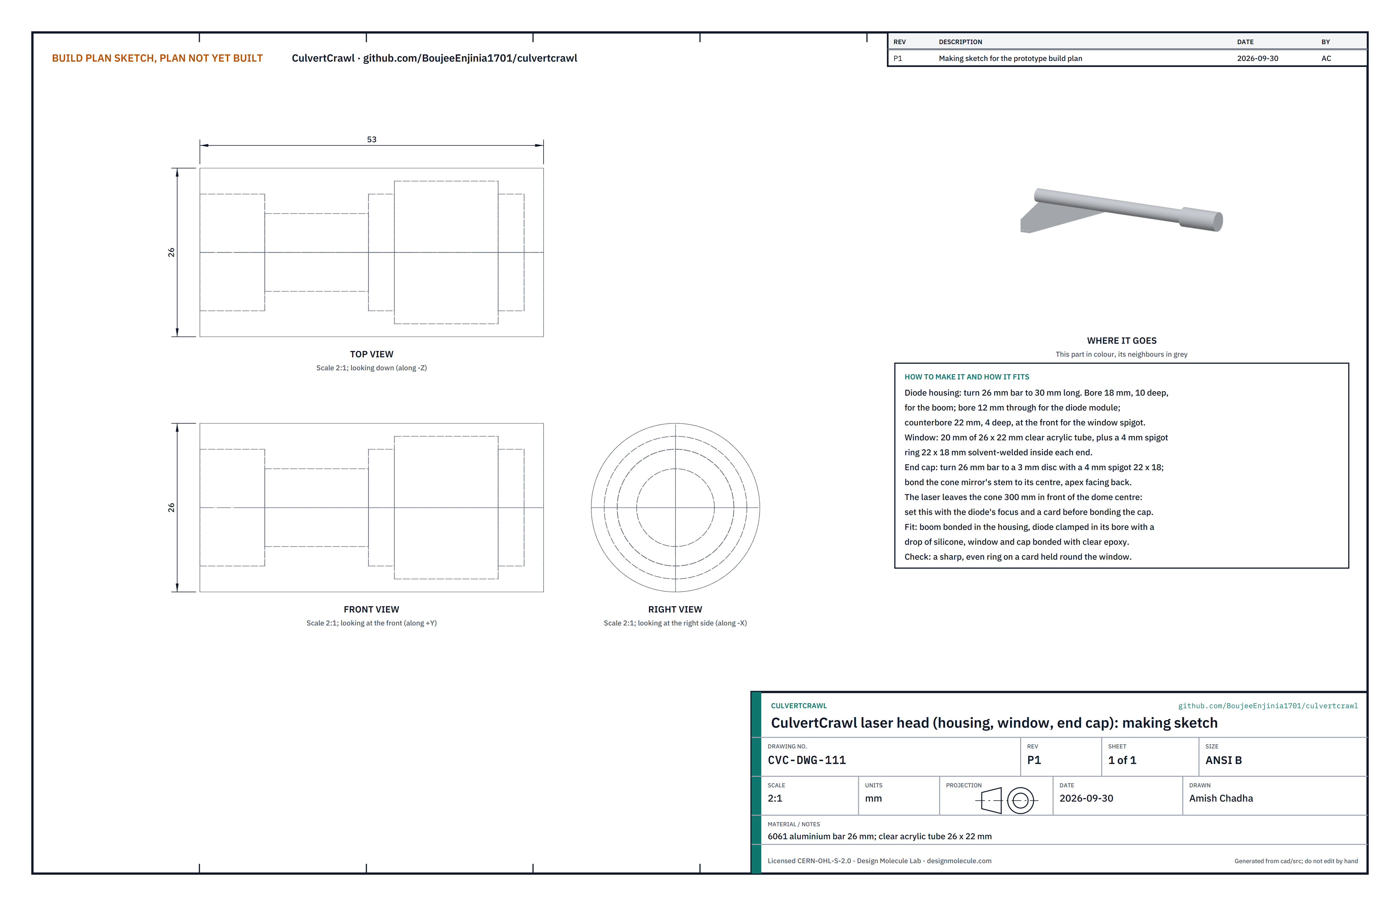
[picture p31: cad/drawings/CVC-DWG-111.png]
Figure 24. Making sketch of the laser head


*Figure 24. Laser head making sketch (CVC-DWG-111).*

**What it is and what it is made from.** The head at the end of the boom that turns the laser beam into a disc of light. A machined aluminium housing and end cap (26 mm bar) and a clear acrylic window tube 26 mm outside, 22 mm inside.

**How to make it.**

1. Diode housing: turn 26 mm bar 30 mm long. Bore 18 mm, 10 mm deep, at the back for the boom; bore 12 mm through for the laser module; counterbore 22 mm, 4 mm deep, at the front.
2. Window: cut 20 mm of the tube and solvent-weld a 4 mm spigot ring (22 mm outside, 18 mm inside) into each end.
3. End cap: turn a 3 mm disc 26 mm across with a 4 mm spigot 22 mm outside, 18 mm inside. Bond the cone mirror's stem to its centre with the cone's point facing back.
4. Clamp the laser module in its bore with a drop of silicone. With the diode lit at low power in a dark room, set its focus so the ring on a card held round the window is sharp, and check that the ring leaves the cone 300 mm in front of the hull's front face.
5. Bond the boom into the housing, the window onto the housing and the cap into the window with clear epoxy.

**How it fits the parts next to it.**

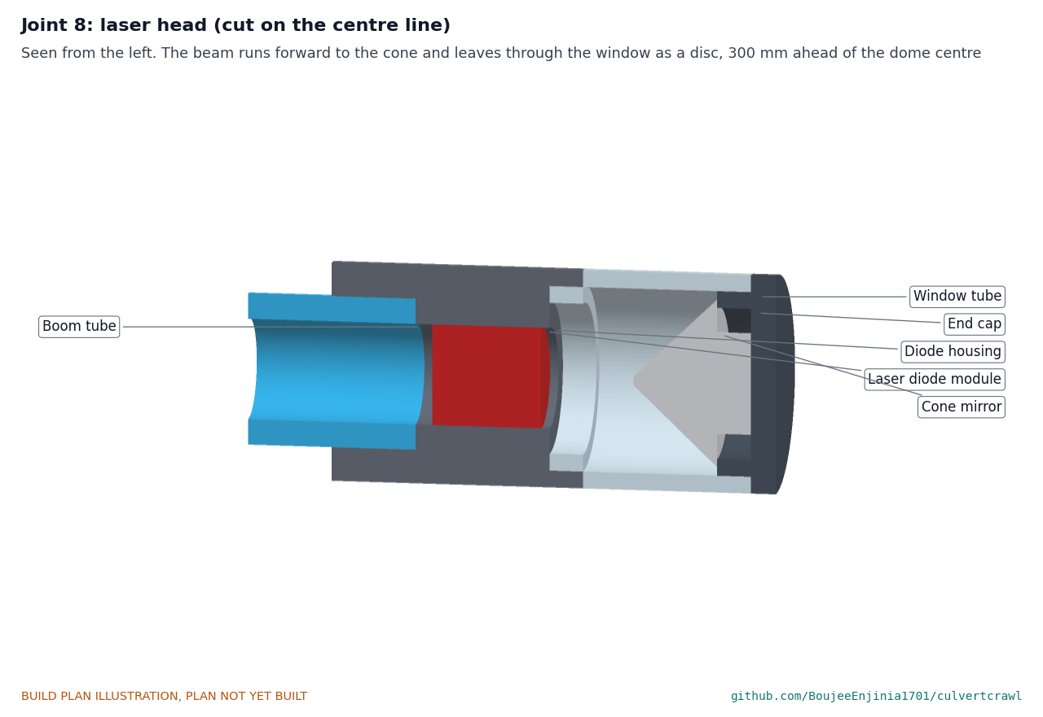
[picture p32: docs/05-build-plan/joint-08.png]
Figure 25. Joint 8: laser head


*Figure 25. The beam runs forward to the cone and leaves through the window as a thin disc of light.*

**Check before moving on.** A sharp, even ring all round on a card held round the window.

### 3.13 Bought rear fittings: penetrator, strain relief, eye bolt

**What to buy.** An M10 IP68 cable penetrator (or gland) for 7 mm cable; a bend restrictor for 7 mm cable; an M8 forged eye bolt (DIN 580 class, working load 1.4 kN or more); the 60 m hybrid tether (two twisted pairs, two 0.75 mm² power wires, an aramid strength member of 1 kN or more, about 7 mm across).

**What to do to them.** Strip back the tether's jacket about 150 mm from the crawler end and break the aramid member out; tie it to the eye bolt with a round turn and two half hitches, leaving the cable slack between the eye and the penetrator (Figure 9). Pot the penetrator to the cable as its maker says.

### 3.14 Reel side frames and spacers

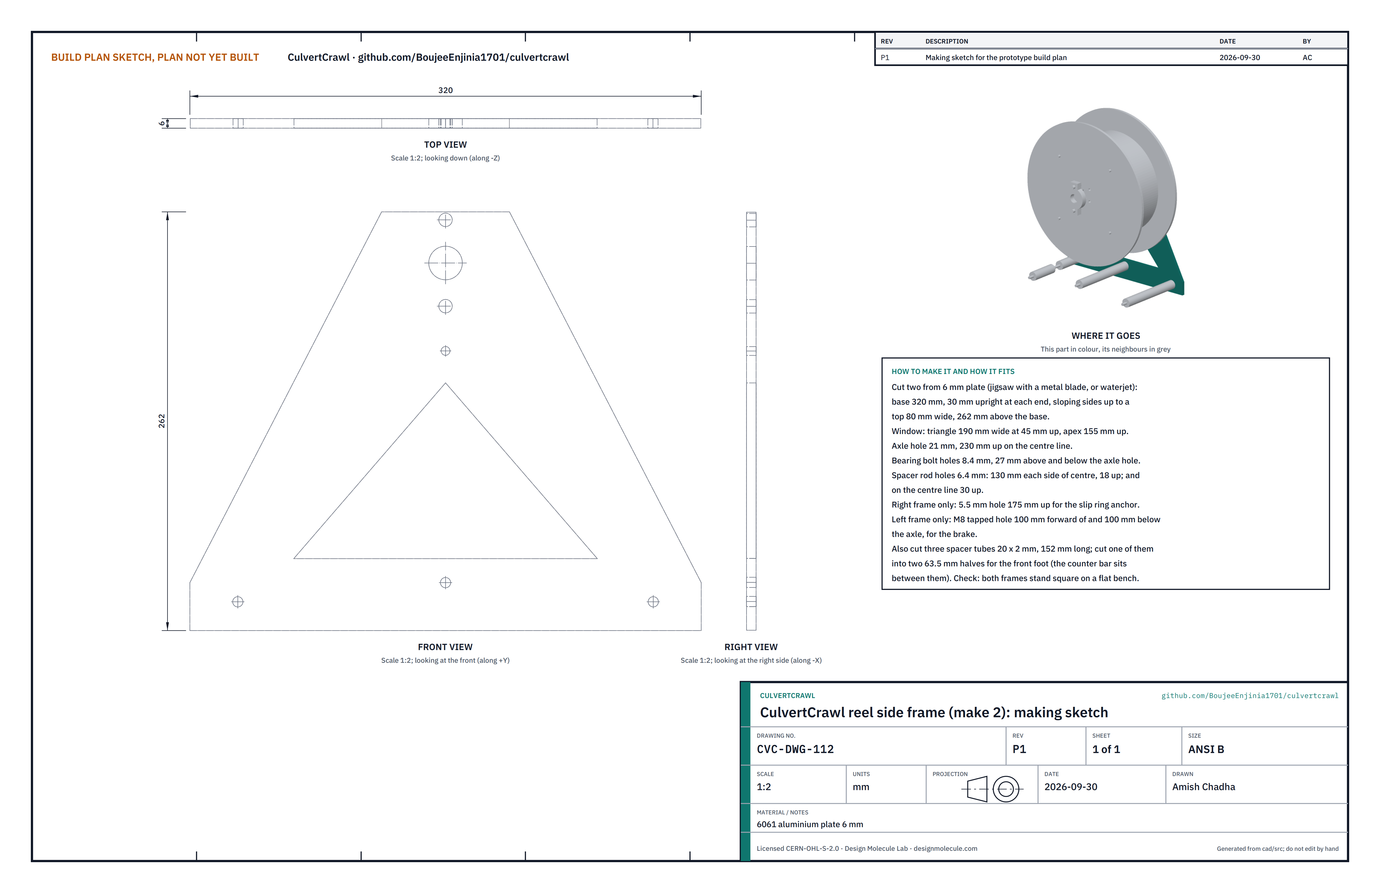
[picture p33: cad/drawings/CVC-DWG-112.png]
Figure 26. Making sketch of the reel side frame


*Figure 26. Reel side frame making sketch (CVC-DWG-112).*

**What it is and what it is made from.** The two A-shaped plates that carry the reel's bearings, joined at the bottom by three spacer tubes. 6061 aluminium plate 6 mm; aluminium tube 20 x 2 mm.

**How to make it.**

1. Cut two frames (jigsaw with a metal blade, or waterjet): base 320 mm, a 30 mm upright at each end, sloping sides up to a top 80 mm wide, 262 mm above the base.
2. Cut the triangular window: 190 mm wide at 45 mm up, its point 155 mm up.
3. Drill a 21 mm axle hole on the centre line 230 mm up, and two 8.4 mm bearing bolt holes 27 mm above and below it.
4. Drill 6.4 mm spacer rod holes 130 mm each side of the centre line, 18 mm up, and on the centre line 30 mm up.
5. Right frame only: a 5.5 mm hole 175 mm up on the centre line for the slip ring anchor. Left frame only: an M8 tapped hole 100 mm toward the counter side and 100 mm below the axle, for the brake.
6. Cut three spacer tubes 152 mm long; cut one of them into two 63.5 mm halves for the front foot (the counter bar fits between them).

**How it fits the parts next to it.** The frames stand 152 mm apart on the spacer tubes, clamped by M6 tie rods with nuts outside. The bearings bolt to their outer faces.

**Check before moving on.** Both frames stand square on a flat bench, and the axle holes line up when you sight through them.

### 3.15 Reel drum

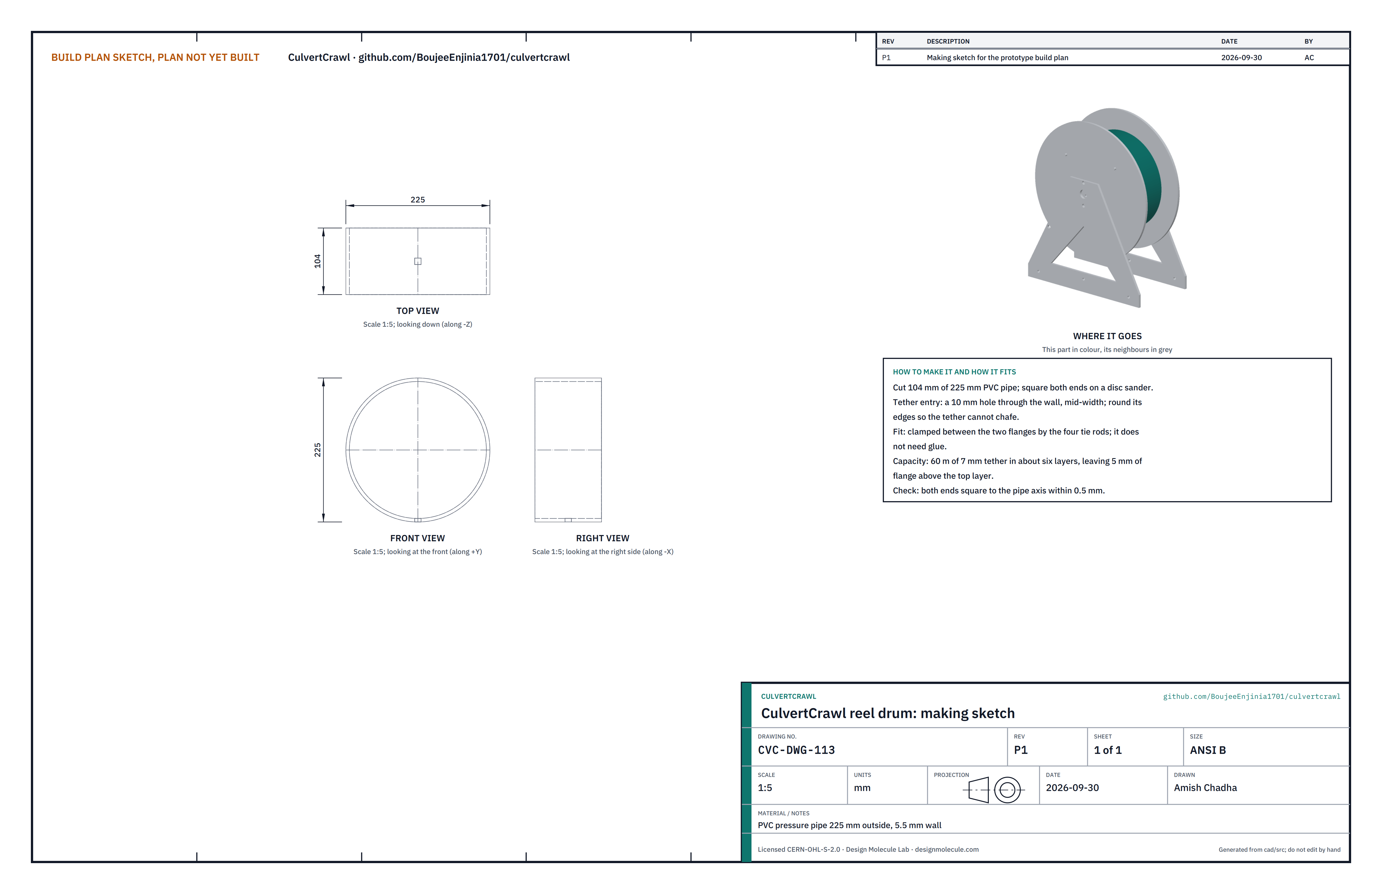
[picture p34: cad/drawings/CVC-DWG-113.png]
Figure 27. Making sketch of the reel drum


*Figure 27. Reel drum making sketch (CVC-DWG-113).*

**What it is and what it is made from.** The core the tether is wound on. PVC pressure pipe 225 mm outside, 5.5 mm wall, 104 mm long.

**How to make it.**

1. Cut 104 mm and square both ends on a disc sander.
2. Drill a 10 mm hole through the wall at mid-width for the tether's inner end; round its edges so the tether cannot chafe.

**How it fits the parts next to it.** It is clamped between the flanges by the four tie rods; no glue.

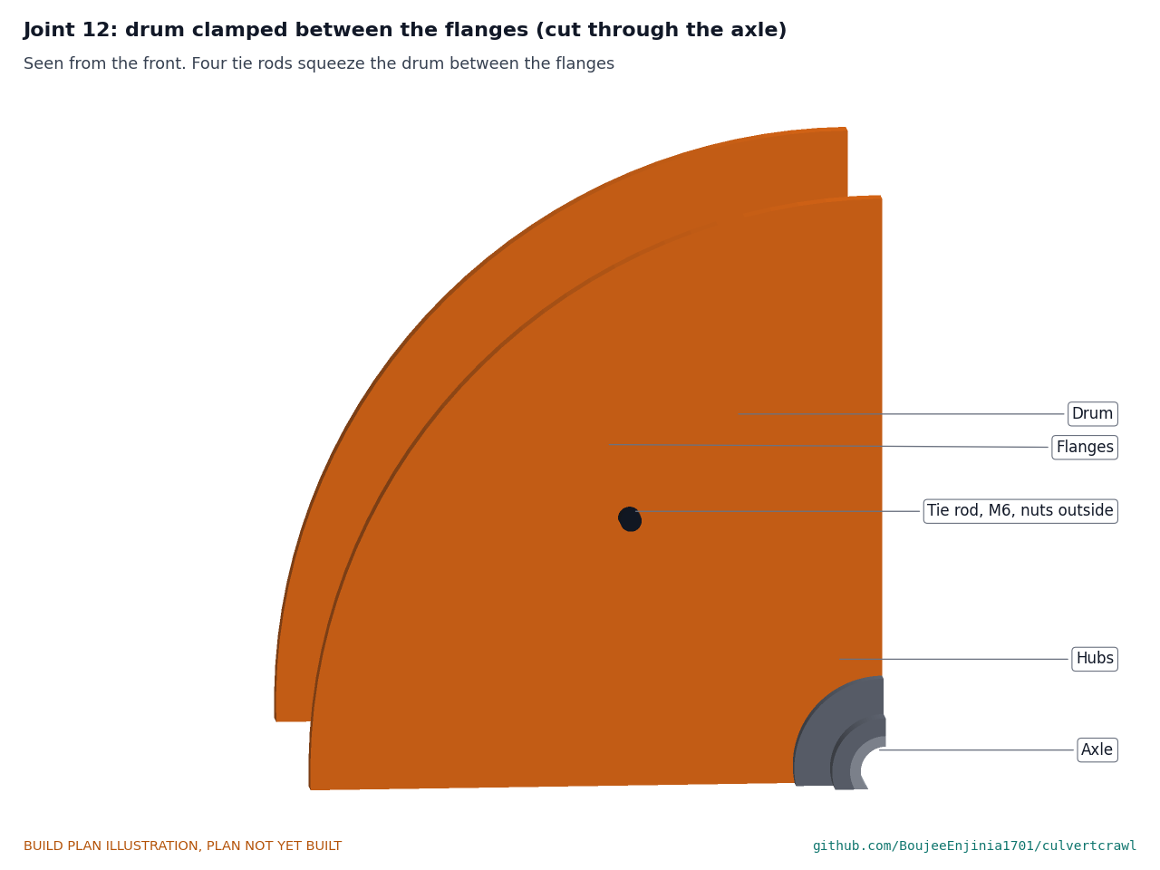
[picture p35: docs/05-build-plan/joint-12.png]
Figure 28. Joint 12: drum between the flanges


*Figure 28. Four M6 tie rods squeeze the drum between the two flanges.*

**Check before moving on.** Both ends are square to the pipe axis within 0.5 mm. 60 m of tether fills it in about six layers, leaving about 5 mm of flange.

### 3.16 Reel flanges (make 2)

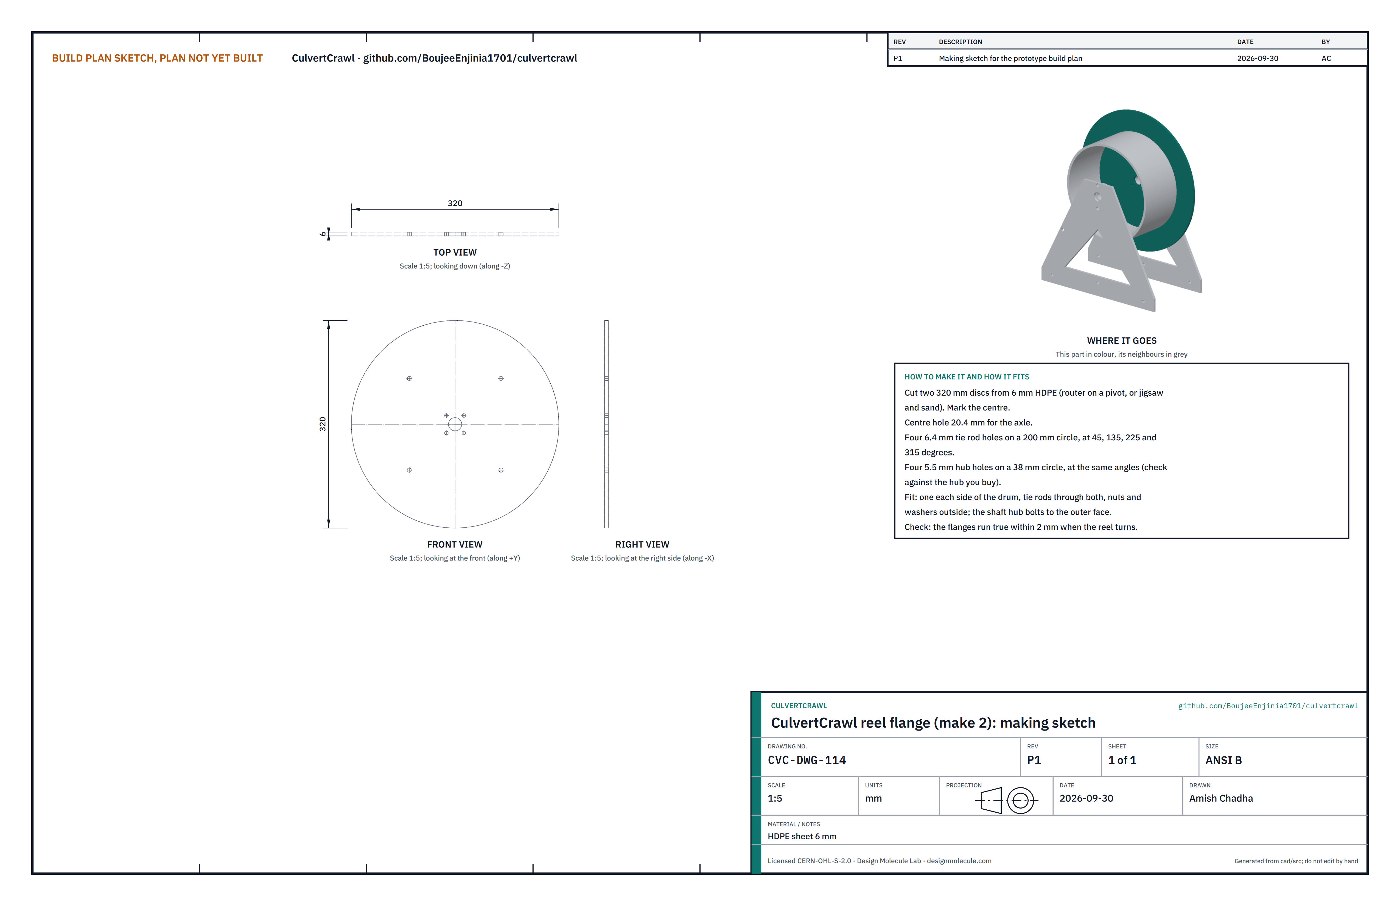
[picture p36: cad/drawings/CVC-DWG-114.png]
Figure 29. Making sketch of the reel flange


*Figure 29. Reel flange making sketch (CVC-DWG-114).*

**What it is and what it is made from.** The two discs either side of the drum. HDPE sheet 6 mm, 320 mm across.

**How to make it.**

1. Cut two 320 mm discs (a router on a pivot, or a jigsaw and sander).
2. Drill a 20.4 mm centre hole, four 6.4 mm tie rod holes on a 200 mm circle and four 5.5 mm hub holes on a 38 mm circle, both sets at 45, 135, 225 and 315 degrees. Check the hub holes against the hub you buy.

**How it fits the parts next to it.** One each side of the drum on the tie rods; a shaft hub bolts to each flange's outer face and grips the axle.

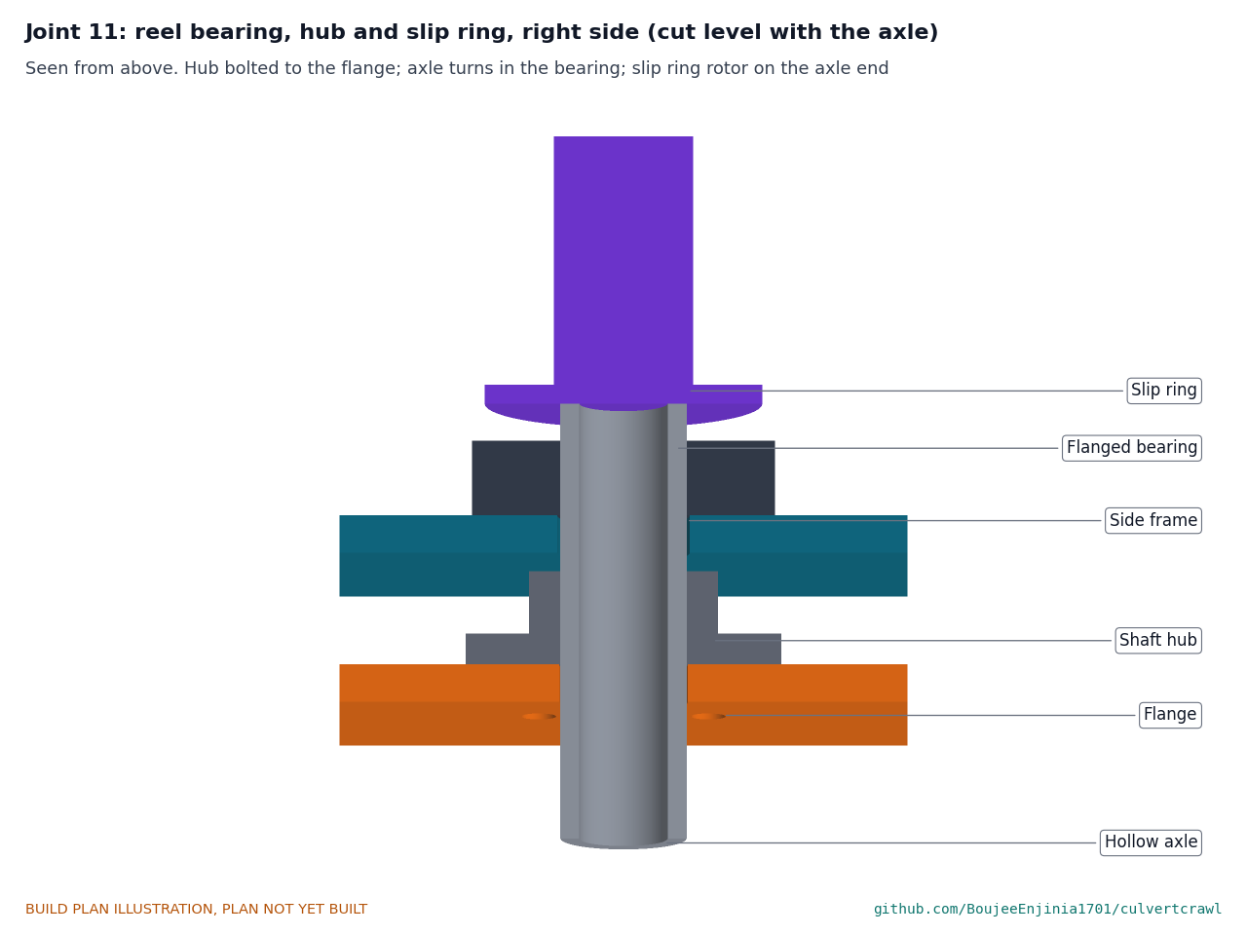
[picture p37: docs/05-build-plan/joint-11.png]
Figure 30. Joint 11: bearing, hub and slip ring


*Figure 30. The hub is bolted to the flange and set-screwed to the axle; the axle turns in the flanged bearing on the side frame; the slip ring's rotor is on the axle end.*

**Check before moving on.** The flanges run true within 2 mm when the reel turns.

### 3.17 Crank and brake

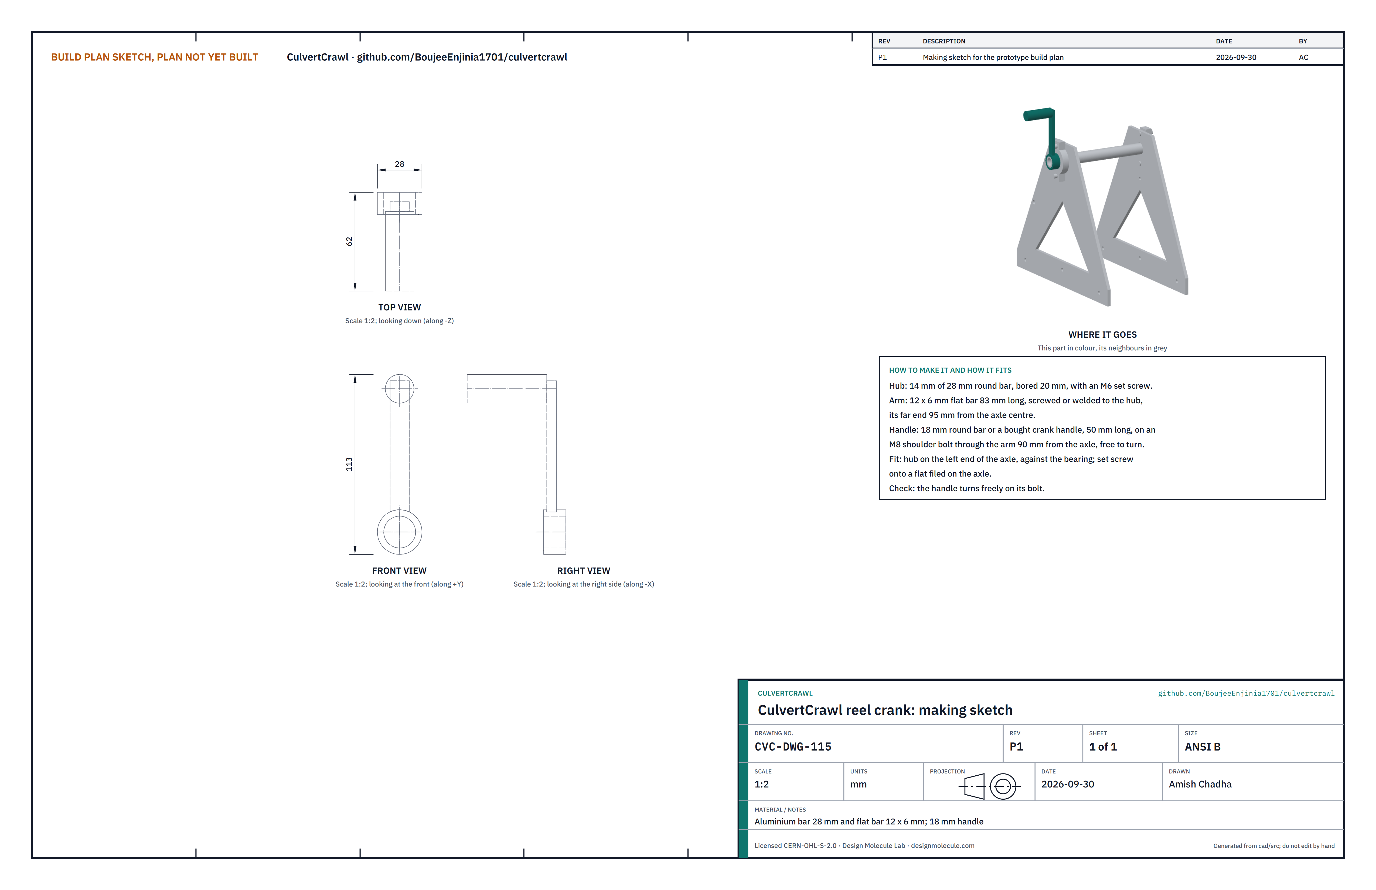
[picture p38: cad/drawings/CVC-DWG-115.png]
Figure 31. Making sketch of the crank


*Figure 31. Crank making sketch (CVC-DWG-115).*

**What it is and what it is made from.** The handle that winds the reel, on the left end of the axle. Aluminium bar 28 mm, flat bar 12 x 6 mm and an 18 mm handle.

**How to make it.**

1. Hub: 14 mm of 28 mm bar, bored 20 mm, with an M6 set screw.
2. Arm: 12 x 6 mm flat bar 83 mm long, screwed or welded to the hub, its end 95 mm from the axle centre.
3. Handle: 18 mm bar or a bought crank handle 50 mm long on an M8 shoulder bolt through the arm, 90 mm from the axle, free to turn.

**How it fits the parts next to it.** The hub sits on the left end of the axle against the bearing, its set screw on a flat filed on the axle. The brake is a bought M8 star-knob screw with a nylon pad on its end, screwed through the left frame so the pad presses on the flange.

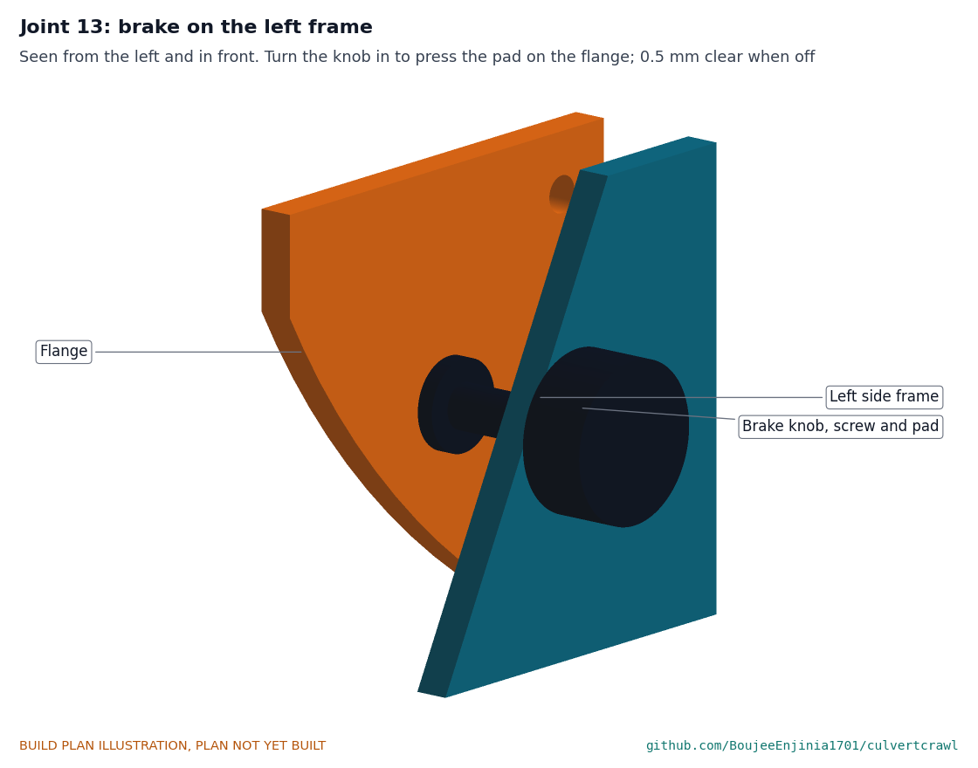
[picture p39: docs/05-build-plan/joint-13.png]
Figure 32. Joint 13: brake


*Figure 32. Turning the knob in presses the pad on the flange; backed off, it is 0.5 mm clear.*

**Check before moving on.** The handle turns freely on its bolt; the brake holds the reel against a firm pull on the tether.

### 3.18 Slip ring anchor bracket

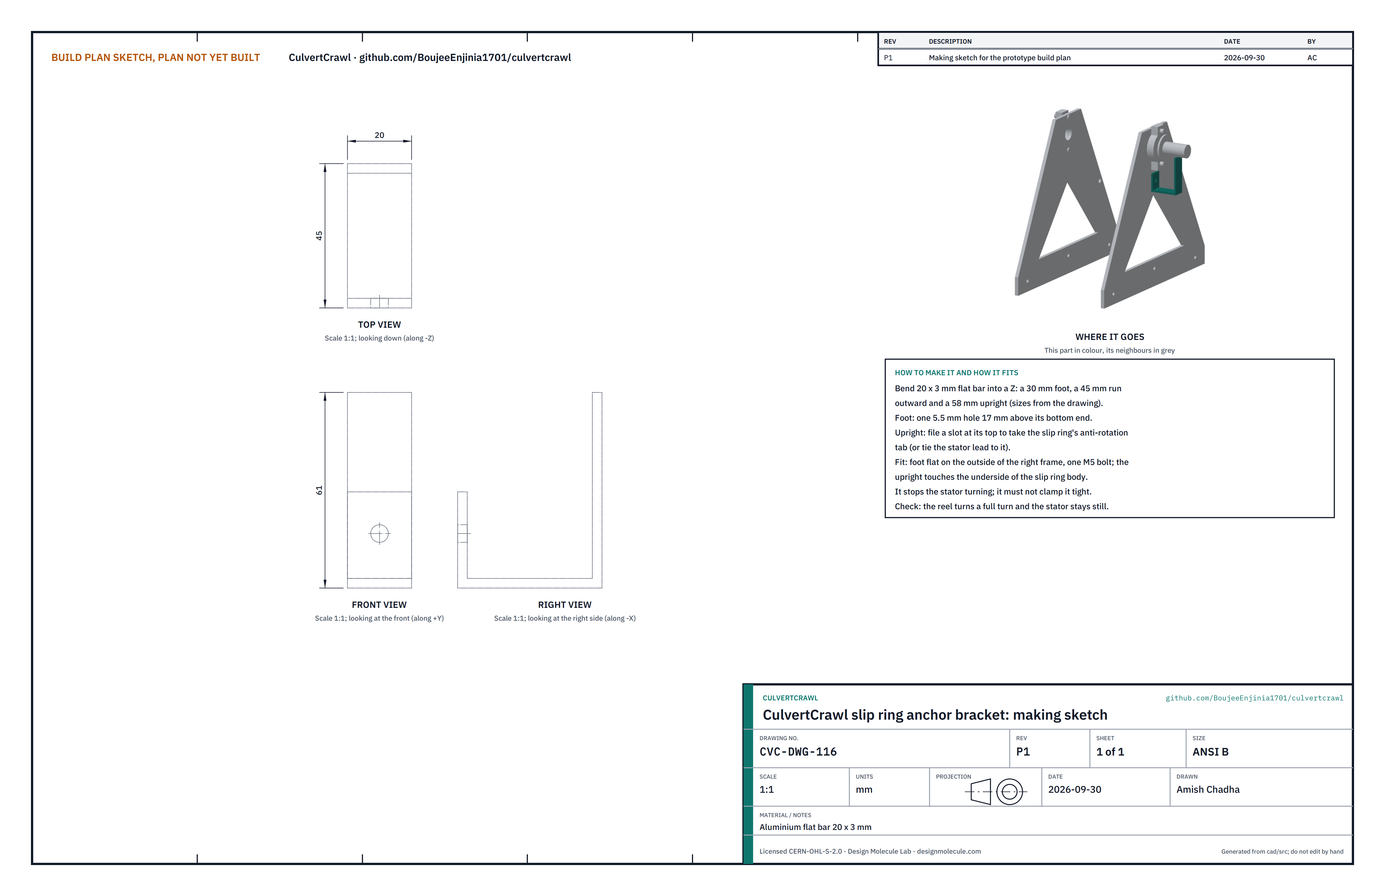
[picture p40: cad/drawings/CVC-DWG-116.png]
Figure 33. Making sketch of the slip ring anchor


*Figure 33. Slip ring anchor making sketch (CVC-DWG-116).*

**What it is and what it is made from.** A small bent strap that stops the slip ring's outer body turning with the reel. Aluminium flat bar 20 x 3 mm.

**How to make it.**

1. Bend it into a Z: a 30 mm foot, a 45 mm run outward and a 58 mm upright.
2. Drill a 5.5 mm hole in the foot 17 mm above its bottom end.
3. File a slot in the top of the upright to take the slip ring's anti-rotation tab, or tie its stator lead to it.

**How it fits the parts next to it.** The foot lies flat on the outside of the right frame on one M5 bolt; the upright touches the underside of the slip ring body. It stops the body turning without clamping it.

**Check before moving on.** Turn the reel a full turn: the slip ring body stays still.

### 3.19 Payout counter bar

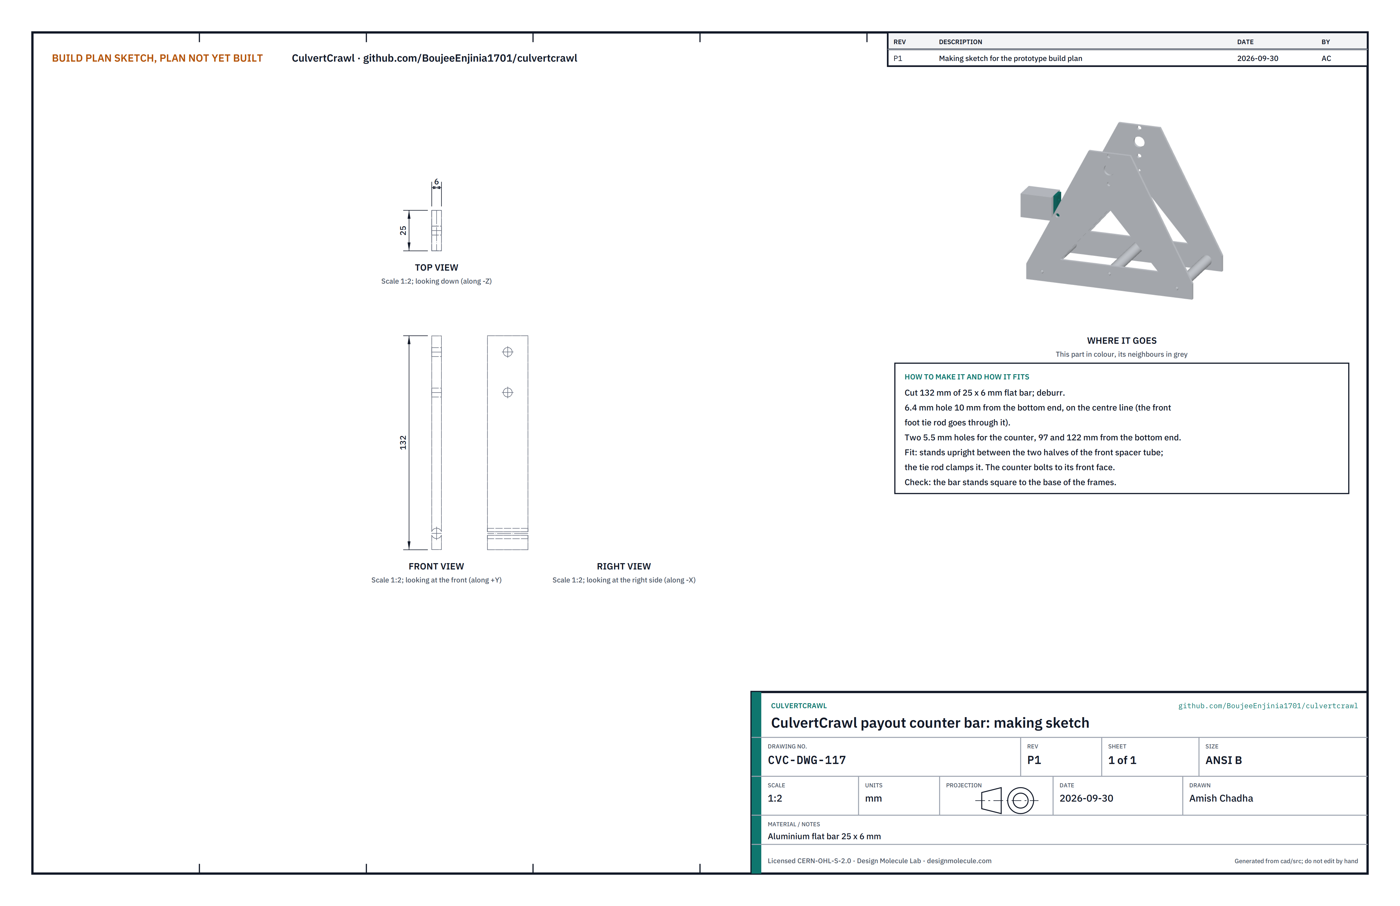
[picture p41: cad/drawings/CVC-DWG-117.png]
Figure 34. Making sketch of the payout counter bar


*Figure 34. Payout counter bar making sketch (CVC-DWG-117).*

**What it is and what it is made from.** An upright bar at the front of the reel frame that carries the payout counter where the tether runs off the drum. Aluminium flat bar 25 x 6 mm, 132 mm long.

**How to make it.**

1. Cut 132 mm and deburr it.
2. Drill a 6.4 mm hole 10 mm from the bottom end for the front tie rod, and two 5.5 mm holes 97 and 122 mm from the bottom end for the counter.

**How it fits the parts next to it.** It stands between the two halves of the front spacer tube and the tie rod clamps it. The counter (a bought 50 mm wheel with a 600-count encoder, a pinch roller and a small USB encoder reader in one box) bolts to its front face.

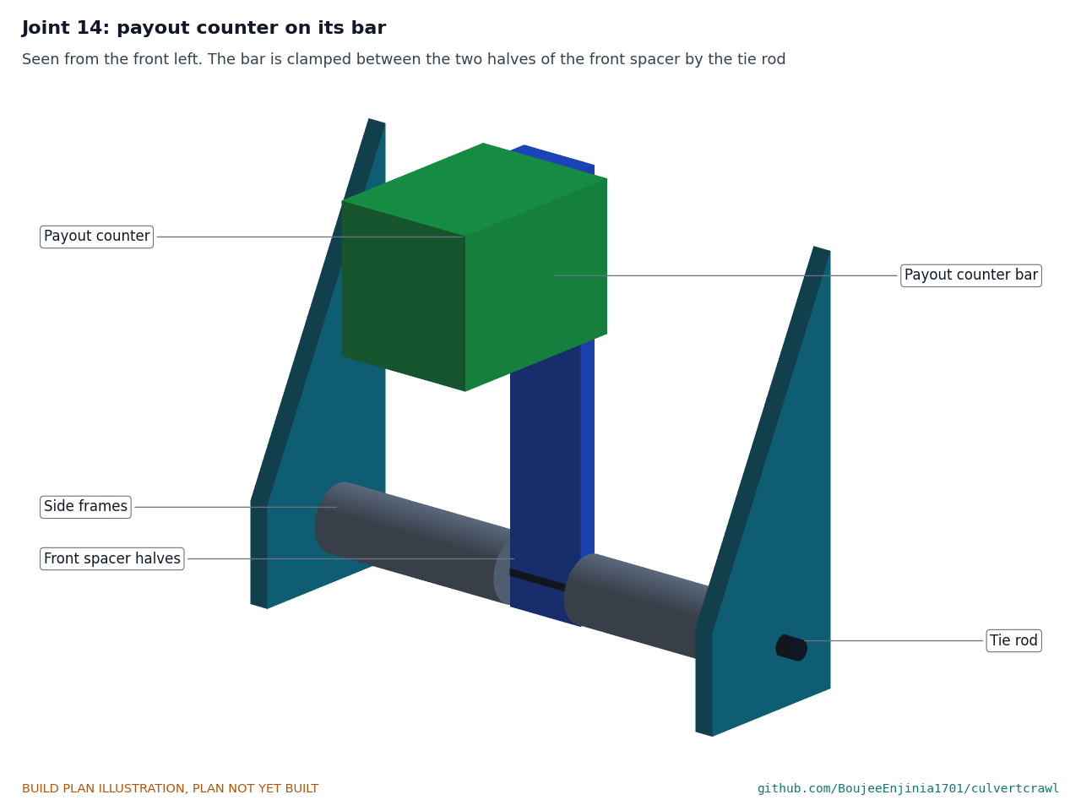
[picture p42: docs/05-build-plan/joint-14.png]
Figure 35. Joint 14: payout counter on its bar


*Figure 35. The bar is clamped between the two halves of the front spacer.*

**Check before moving on.** The bar stands square to the frames' base.

### 3.20 Surface box chassis: base board and posts

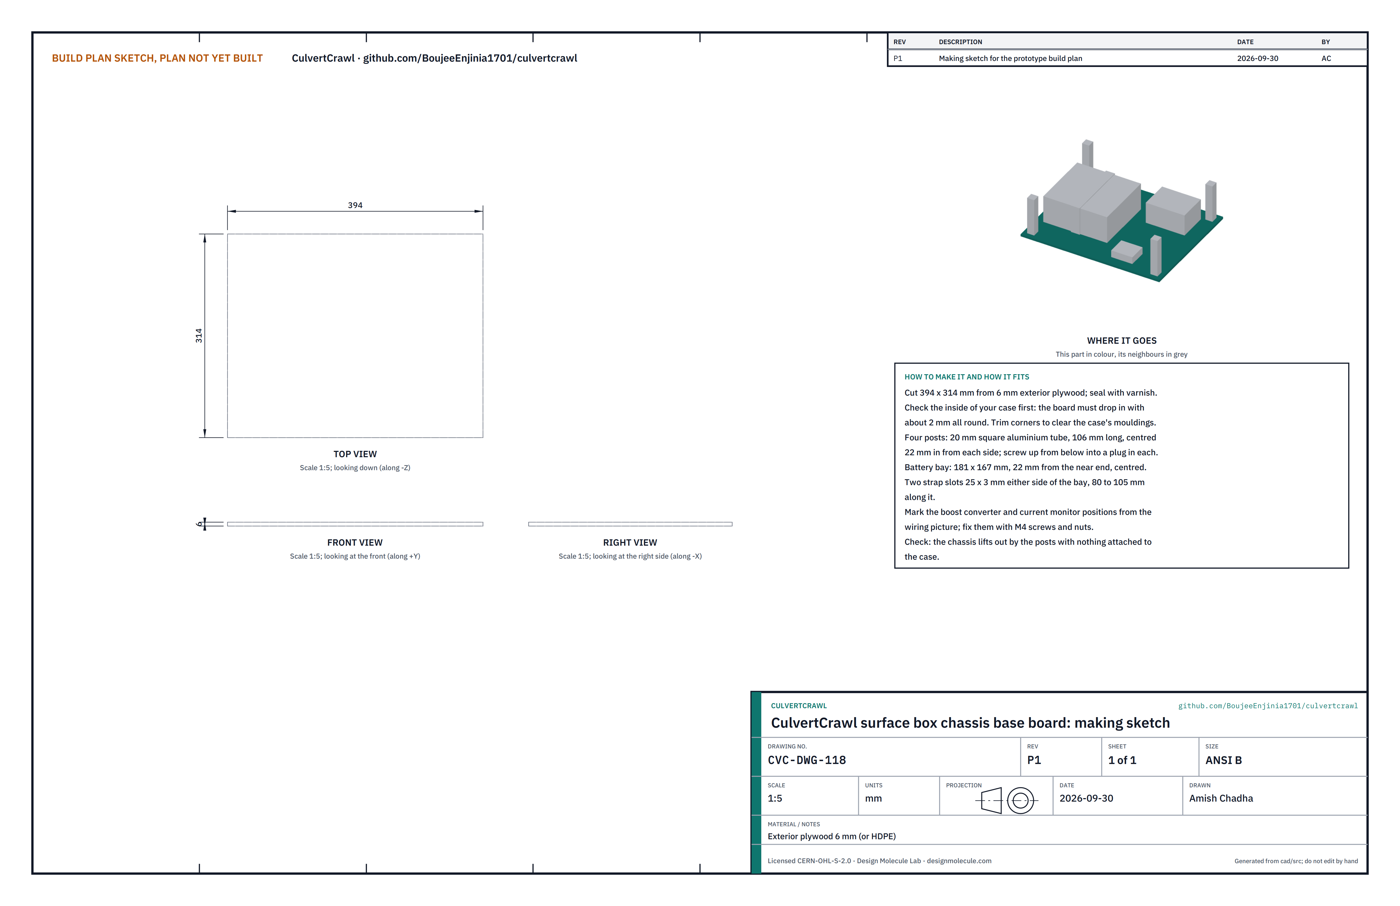
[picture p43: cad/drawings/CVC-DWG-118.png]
Figure 36. Making sketch of the chassis base board


*Figure 36. Chassis base board making sketch (CVC-DWG-118).*

**What it is and what it is made from.** A board that drops into the bottom of the bought case, carrying the battery, the boost converter and the current monitor, with four posts that hold the panel. Exterior plywood 6 mm (or HDPE); aluminium square tube 20 mm.

**How to make it.**

1. Measure the inside of your case first, then cut the board about 2 mm smaller all round (394 x 314 mm in the model); trim its corners to clear the case's mouldings and seal it with varnish.
2. Cut four posts 106 mm long from the square tube; press a plastic plug into each end and screw them up from below, centred 22 mm in from each side.
3. Mark the battery bay, 181 x 167 mm, 22 mm from the board's end nearest the reel; cut two 25 x 3 mm strap slots either side of it.
4. Mark and drill the converter and monitor positions from Figure 15 and fix them with M4 screws and nuts.

**How it fits the parts next to it.** The board lies on the case floor; the battery lies on its side in its bay, held by the strap; the panel screws to the post tops. Nothing is screwed to the case.

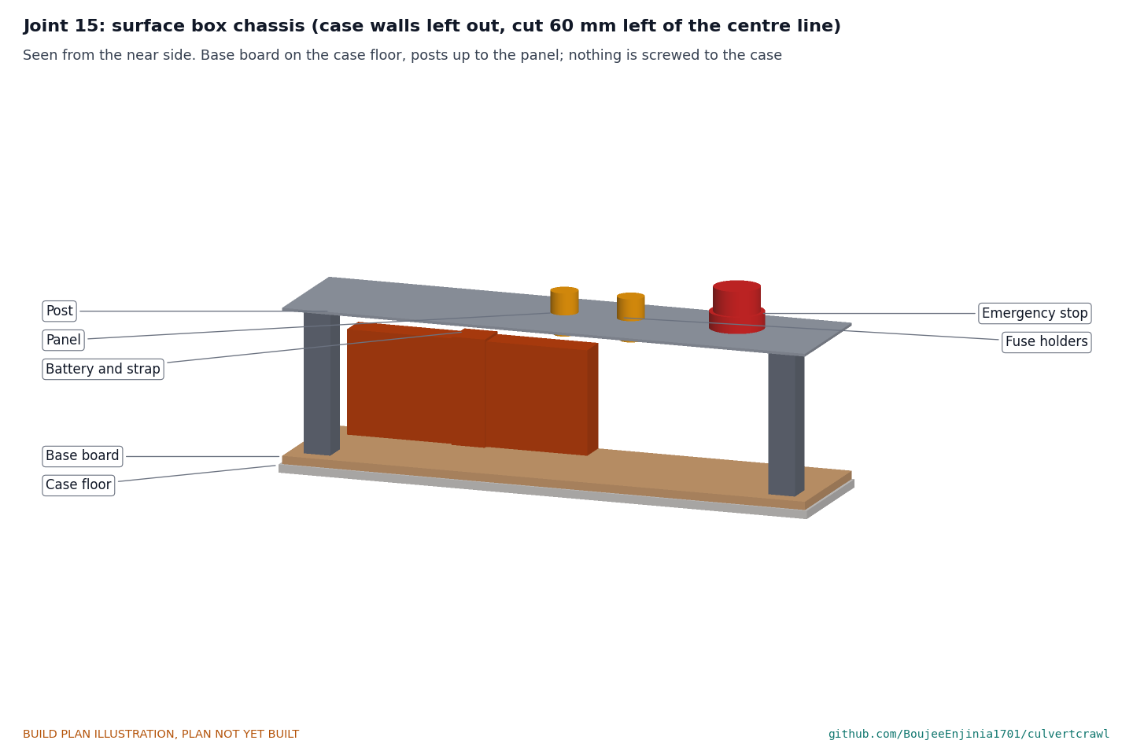
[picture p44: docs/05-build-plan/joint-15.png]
Figure 37. Joint 15: surface box chassis


*Figure 37. Base board on the case floor, posts up to the panel, battery strapped down (case walls left out of the picture).*

**Check before moving on.** The chassis lifts out by its posts with nothing left attached to the case.

### 3.21 Surface box panel

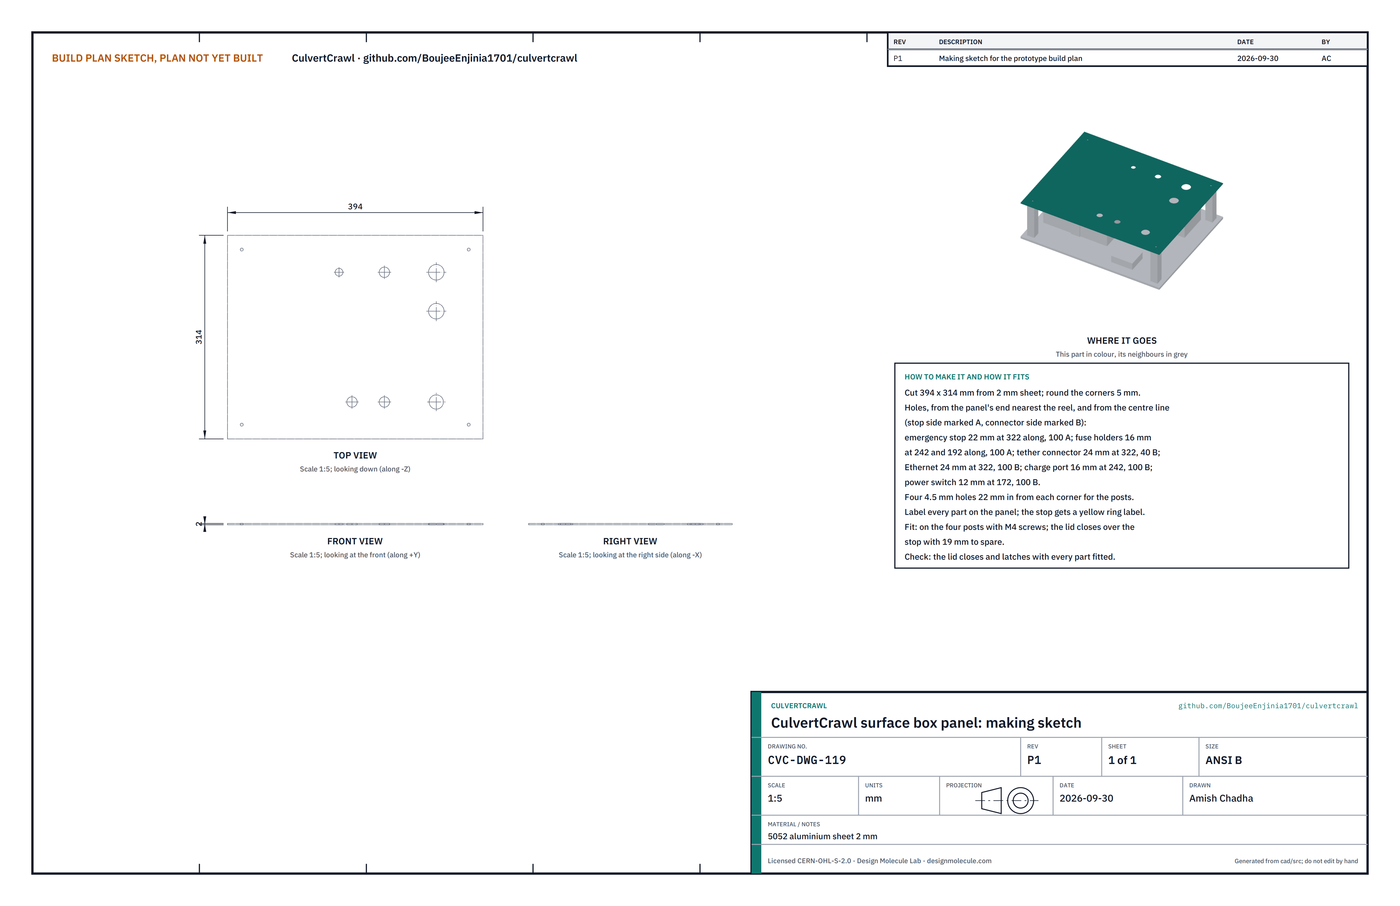
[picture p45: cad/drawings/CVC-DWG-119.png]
Figure 38. Making sketch of the chassis panel


*Figure 38. Chassis panel making sketch (CVC-DWG-119).*

**What it is and what it is made from.** The top plate of the chassis, under the case lid, carrying the controls. 5052 aluminium sheet 2 mm, 394 x 314 mm.

**How to make it.**

1. Cut it and round the corners 5 mm.
2. Measured from the end nearest the reel and from the centre line, on side A: the emergency stop, 22 mm hole at 322 along, 100 out; two fuse holders, 16 mm holes at 242 and 192 along, 100 out. On side B: the tether connector, 24 mm at 322 along, 40 out; the Ethernet bulkhead, 24 mm at 322 along, 100 out; the charge port, 16 mm at 242 along, 100 out; the power switch, 12 mm at 172 along, 100 out.
3. Four 4.5 mm holes 22 mm in from each corner for the posts.
4. Label every part; put a yellow ring label behind the stop.

**How it fits the parts next to it.** Four M4 screws into the posts; the lid closes over the stop with 19 mm to spare.

**Check before moving on.** With every part fitted, the lid closes and latches.

### 3.22 Other bought components

Buy to specification, not brand. Line numbers are those of the bill of materials.

- **Electronics (line 4).** Raspberry Pi 4 Model B 2 GB; dual DC motor driver with current limit; 36 to 75 V input to 12 V buck converter; 12 to 5 V buck converter; 6-axis IMU; leak sensor; microSD card; 4 mm spacers and 20 mm M2.5 standoffs.
- **Camera and dome (line 5).** 12 MP IMX708 camera board with an M12 lens mount; 180 degree class circular fisheye M12 lens whose image circle fits inside the sensor height; 60 mm acrylic dome port with a 72 mm, 5 mm flange and its O-ring.
- **LEDs (line 6).** Eight 1 W high-CRI white LEDs on 10 mm round aluminium boards, and a dimmable constant-current driver that can follow a frame signal.
- **Laser (line 7).** A Class 2 (1 mW or less) 520 nm laser module 12 mm across; a 90 degree conical mirror with a base 20 mm or less; clear acrylic tube 18 x 12 mm and 26 x 22 mm; clear cast acrylic sheet 8 mm.
- **Reel parts (line 10).** A 6-circuit slip ring rated for 100 Mbit/s Ethernet, with an anti-rotation tab; two 20 mm bore 2-bolt flanged bearings; two 20 mm flange shaft hubs; 20 mm aluminium tube (14 mm bore) about 210 mm long; an M8 star-knob screw with a nylon pad; the payout counter (50 mm wheel, 600-count encoder, pinch roller, USB reader).
- **Surface box (line 11).** A rugged waterproof case about 410 x 330 x 175 mm outside; a 12.8 V 20 Ah LiFePO4 battery with its own BMS; a 12 to 48 V 100 W boost converter; 10 A and 2 A fuses in panel holders; a latching emergency stop with a normally closed contact rated 10 A DC; a tether current monitor with a 1.5 A cutoff relay; tether, Ethernet and charge connectors; a power switch; a battery strap.
- **Gamepad (line 12).** Any USB gamepad.
- **Fixings and consumables (line 13).** Stainless: 10 x M4 x 12 pan-head screws (lid); 10 x M4 countersunk screws (side plates); 4 x M4 x 16 screws (bezel); 2 x M4 x 10 and 2 x M3 x 16 with nyloc nuts (fin); 4 x M3 x 6 (tray); M8 eye bolt; M6 and M8 shoulder bolts; seven M6 tie rods with nuts and washers; 4 x M8 bearing bolts; O-rings for the lid, the dome and the six screw seals; silicone grease; potting epoxy; acrylic solvent cement; thermal pad; desiccant; cable ties and heat-shrink.

## 4. Putting it together

In each picture the parts already fitted are grey and the part being fitted is in colour, with an arrow showing the way it goes in.

### Step 1: hull onto the ballast plate

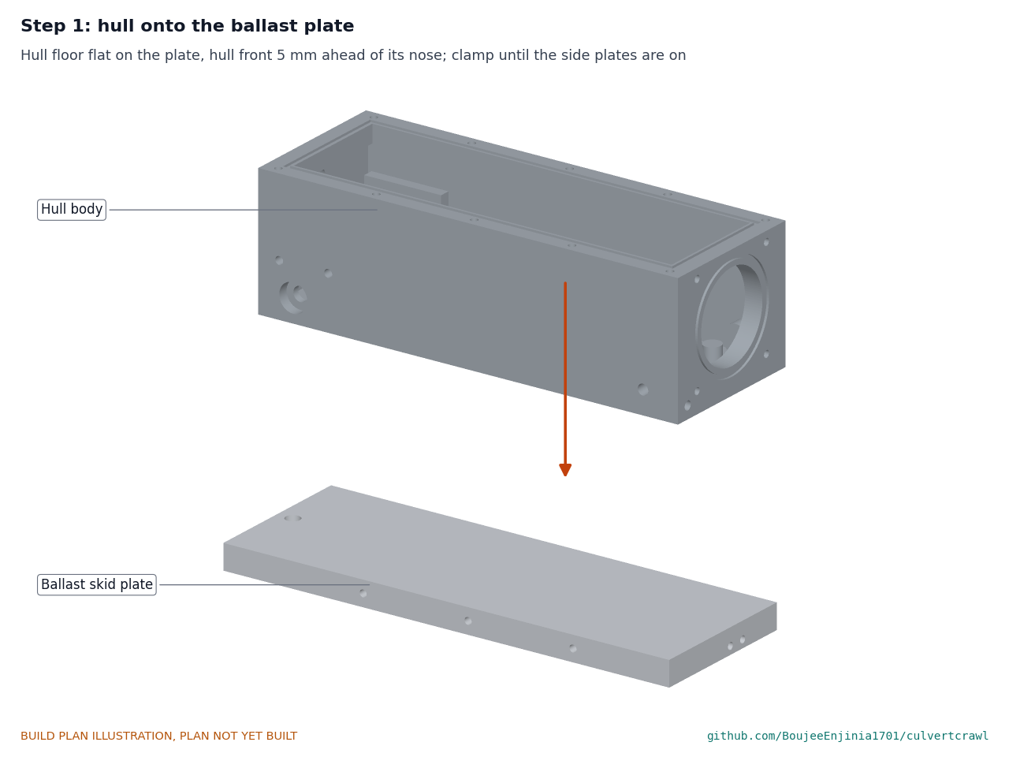
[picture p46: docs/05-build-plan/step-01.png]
Step 1


Stand the hull on the plate with its front 5 mm ahead of the plate's nose and its sides flush with the plate's sides. Clamp the two together until the side plates are on.

### Step 2: shaft lip seals into the side walls

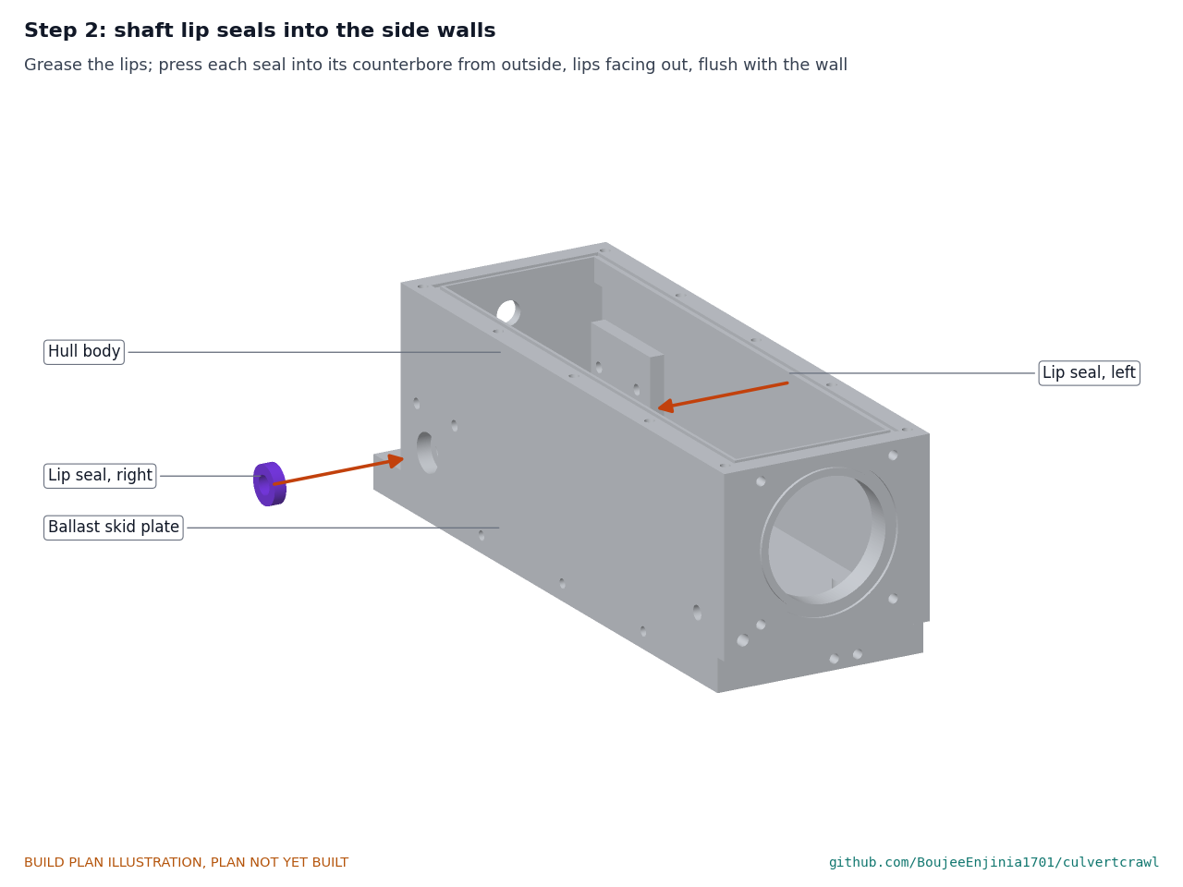
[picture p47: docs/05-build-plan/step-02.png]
Step 2


Grease the lips and press each seal into its counterbore from outside, lips facing out, flush with the wall face. Use a socket the size of the seal's outer ring, not the lips.

### Step 3: worm gear motors into the hull

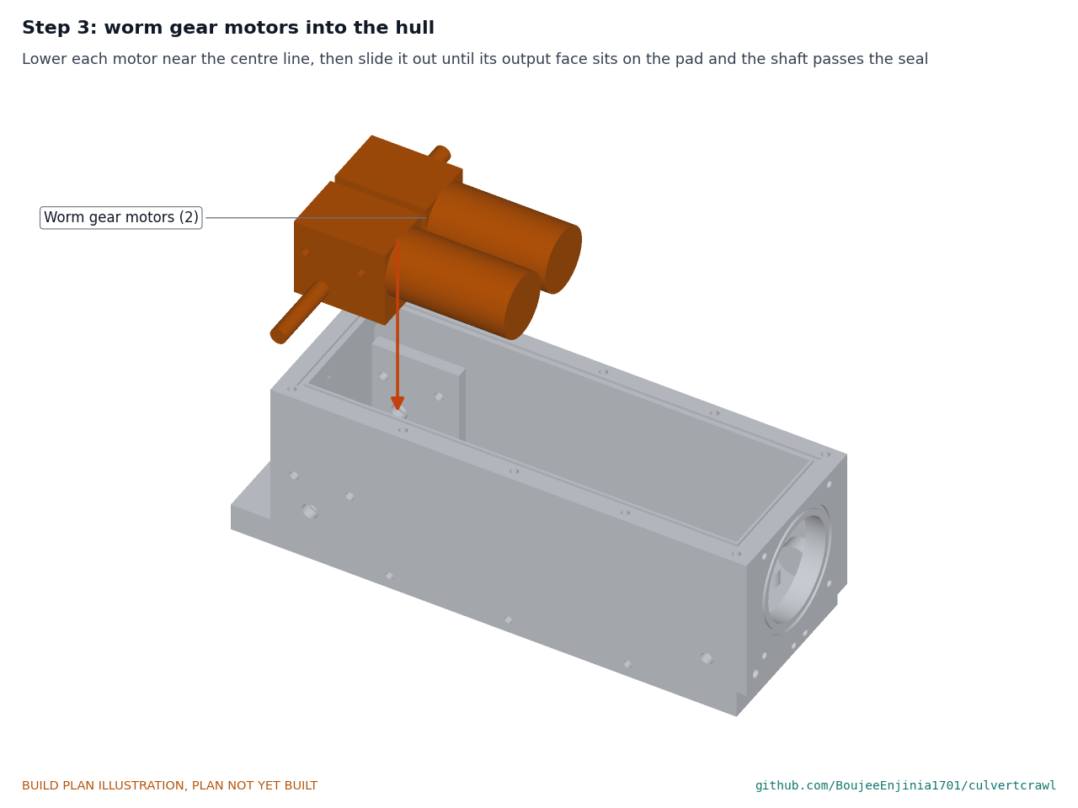
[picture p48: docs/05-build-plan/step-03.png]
Step 3


Lower each motor in near the centre line (it passes the rim that way), then slide it out until its output face sits flat on the drive pad and its shaft passes through the seal.

### Step 4: side plates on

Step 4

Put a small greased O-ring in the counterbore round each gearbox screw hole. Hold each plate flat on the hull and ballast sides; fit the two M4 countersunk screws through the plate and wall into the gearbox, then the three into the ballast side, with medium threadlocker. Tighten evenly, then take the clamps off. **Hold point:** each motor shaft turns by hand without binding.

### Step 5: sprockets, idlers and belts

Step 5

Slide each sprocket onto its shaft and tighten its set screw on the flat. Loop the belt round the sprocket, hold the idler in the belt's other end and push the M6 shoulder bolt through the idler and side plate into the hull boss; tighten it.

### Step 6: electronics tray onto the floor pads

Step 6

Four M3 x 6 screws into the pads.

### Step 7: Pi 4 and deck

Step 7

The Pi on four 4 mm spacers, the thermal pad under its heat sink; the deck on four 20 mm standoffs. Wire the motors, encoders, converters, driver and IMU as Figure 15 shows. **Hold point:** the wiring checks of section 3.6.1 pass.

### Step 8: camera mount and camera onto the front wall

Step 8

Four M3 screws into the front wall from inside. Connect the camera cable to the Pi.

### Step 9: dome port onto the front wall

Step 9

Lay the greased O-ring in the front wall groove and centre the dome flange over it.

### Step 10: front bezel over the dome

Step 10

Pass the LED leads into the hull through the lead hole first. Fit the bezel over the dome with four M4 x 16 screws, tightened a little at a time in a cross pattern until the flange is gripped evenly.

### Step 11: fin bracket onto the ballast nose

Step 11

Two M4 x 10 screws into the nose, the forward leg just right of the centre line.

### Step 12: fin, boom and laser head

Step 12

With the boom and head already bonded to the fin, bolt the fin to the bracket's forward leg with two M3 x 16 bolts and nyloc nuts. Run the laser leads down the fin's back edge and into the lead hole with the LED leads; pot the lead hole from outside with epoxy.

### Step 13: tether penetrator, strain relief and eye bolt

Step 13

Screw the eye bolt into the ballast plate and lock it with its nut. Fit the potted penetrator in the rear wall, nut inside, and slide the strain relief onto it. Tie the aramid member to the eye with slack in the cable. Connect the tether's power wires to the buck converter and its pairs to the Ethernet plug.

### Step 14: lid on

Step 14

Put a fresh desiccant pack in. Clean and grease the O-ring and lay it in the rim groove. Fit the lid with ten M4 screws in a cross pattern, and the test plug. **Hold point:** the leak test of section 3.1 passes before the crawler goes near water.

### Step 15: reel frame

Step 15

Three spacer tubes between the two frames on M6 tie rods, the counter bar between the two halves of the front spacer. Snug the nuts.

### Step 16: bearings onto the frames

Step 16

One flanged bearing on the outside of each frame with two M8 bolts; leave its set screws loose.

### Step 17: drum, flanges and hubs

Step 17

Stand the drum between the flanges, push the four tie rods through and tighten their nuts evenly. Bolt a shaft hub to each flange's outer face.

### Step 18: drum into the frame, axle through

Step 18

Hold the drum between the frames and slide the axle in through one bearing, both hubs and the other bearing. Centre the drum, tighten the hub set screws, then the bearing set screws. Pass the tether's inner end through the drum hole and along the hollow axle to the slip ring end.

### Step 19: crank, brake, slip ring and anchor

Step 19

The crank on the left axle end; the brake knob into the left frame; the slip ring's rotor fixed to the right axle end, its rotor leads joined to the tether's inner end; the anchor bolted to the right frame so it catches the slip ring body.

### Step 20: payout counter onto its bar

Step 20

Two M5 bolts. Thread the tether between the wheel and the pinch roller, then wind the tether onto the drum evenly.

### Step 21: battery, converter and posts onto the base board

Step 21

The battery on its side in its bay, strapped down; the boost converter and current monitor on M4 screws; the four posts screwed up from below. **Hold point:** the battery fuse stays out.

### Step 22: panel onto the posts

Step 22

Fit and wire the stop, fuse holders, connectors and switch to the panel first, then fix the panel to the posts with four M4 screws.

### Step 23: chassis into the case

Step 23

Lower the chassis into the case; nothing is screwed to the case. Close the lid and check it latches.

## 5. First checks

These are the checks a TRL 4 test report would record; this plan only lists them. Requirement numbers are those of CVC-REQ-001.

*Table 2. First checks.*

| Check | Requirement | How | Pass when |
| --- | --- | --- | --- |
| Hull leak test | R7 | 20 kPa of air through the test plug, everything fitted | Less than 1 kPa drop in 10 minutes |
| Size and fit | R1 | Measure; roll the crawler through a 300 mm pipe section | 180 mm wide and 140 mm high or less; nothing touches the wall |
| Mass | R10 | Weigh the crawler, the reel with tether and the surface box | Crawler about 6.6 kg; no item over 10 kg; kit 25 kg or less |
| Tether voltage and stop | R11 | Surface box on, crawler connected, meter at the crawler's buck input; then press the stop | About 46 V or more at the crawler; 0 V within a second of the stop |
| Overcurrent cutoff | R11 | Bench load on the tether output, raised slowly | Output cuts at 1.5 A |
| Drive and hold | R8 | Drive forward and back on a bench; then stand the crawler on a 5 % ramp, power off | Both tracks turn both ways; no creep on the ramp |
| Video | R4 | Stream to the laptop | 1080p at 25 frames per second, with the overlay |
| Laser ring | R5, R11 | Crawler in a 300 mm reference pipe in the dark; laser module's class label checked | A complete, sharp ring except the thin strip behind the fin; module Class 2 |
| Payout counter | R6 | Pull 10 m of tether out past a tape | The count reads 10 m within 0.1 m |
| Recovery | R3 | Tracks locked, pull the crawler by the tether on a bench | It slides; the pull goes to the eye bolt, not the penetrator |

## 6. Safety stops

Stop at each point. Carry on only when everything listed is true.

- **S1. Before the battery comes into the workshop.** Battery voltage 12.0 to 13.6 V; no swelling, dents or leaks; a datasheet from its maker; its BMS present. A charging spot ready on a non-combustible surface with an extinguisher for electrical fires within reach.
- **S2. Before the battery fuse goes in.** All wiring checked end to end with the fuse out; polarity at the boost input checked with a meter, not by wire colour; the stop wired so that pressing it opens the boost input.
- **S3. Before 48 V goes onto the tether.** The 2 A tether fuse fitted; the boost output measured at 48 V on the bench with no load; the overcurrent cutoff tested with a bench load; the stop tested.
- **S4. Before the crawler is powered.** The buck converter's input polarity checked at the penetrator; the motors' tracks off the bench (crawler on a stand) so they can turn freely.
- **S5. Before the laser is switched on.** The laser module's label shows Class 2 (1 mW or less); everyone in the room told; the beam pointed into a pipe or at a wall, never at eye height.
- **S6. Before the crawler goes in water.** The hull leak test of section 3.1 passed within the last day; the test plug and every lid screw tight; the leak sensor tested.
- **S7. Before any pipe work outside the workshop (outside this plan).** A second person; air at the mouth checked with a four-gas monitor; traffic control as the road owner requires; nobody enters the pipe, including to free the crawler; the tether never tied to a vehicle.

## 7. Tools, skills and workspace

**Tools.** A CNC mill or a machine shop for the hull, lid and bezel (send CVC-DWG-101, 102 and 107 and the hull hole picture); a lathe, or the same shop, for the laser housing and end cap; a bench drill; drills 2 to 21 mm; a countersink; M3, M4, M6, M8 and M10 x 1 taps; a hacksaw and a jigsaw with a metal blade; files and a deburring tool; a scriber, square, rule and calipers; a 3D printer for PETG or ASA; a laser cutter or a fine saw for the acrylic fin; a disc sander; a soldering iron, ferrule crimper and wire strippers; a multimeter; a bench power supply with a current limit (0 to 60 V, 0 to 3 A); a bench load; a hand pump with a gauge reading to 30 kPa; a torque screwdriver; a scale to 10 kg.

**Skills.** No certified trade is needed. Basic metalwork (marking out, sawing, drilling, tapping, filing), reading a machining drawing well enough to order parts from a shop, solvent-welding acrylic, potting, through-hole soldering and crimping, safe use of a bench supply, and care with lithium batteries. All circuits are extra-low voltage: 12.8 V at the battery and 48 V on the tether, below the 60 V DC limit. No mains wiring is part of this build; the battery charger must be a certified LiFePO4 charger.

**Workspace.** A bench about 1.5 x 0.75 m; a metalwork corner kept apart from the electronics; a ventilated place for the printer, solvent and epoxy; the charging spot of S1; a dark corner and a short length of 300 mm pipe for the laser check.

**Personal protective equipment.** Safety glasses for cutting, drilling, soldering and solvent work; cut-resistant gloves for bar, sheet and the acrylic; nitrile gloves for epoxy and solvent; hearing protection when sawing; no gloves near a turning drill; laser safety glasses rated for 520 nm if the beam is aligned by eye.

## 8. Where the numbers come from

- Model and constructability checks: `cad/src/model.py` (`python cad/src/model.py --check`, 94 checks); STEP and STL exports in `cad/step/` and `cad/stl/`.
- Pictures: `cad/src/build_plan_media.py`, using `.kit/build_views.py`; written to `docs/05-build-plan/` and `cad/drawings/CVC-DWG-101` to `CVC-DWG-119`.
- General arrangement: `cad/drawings/CVC-DWG-001.pdf`, Rev P3.
- Calculations: `docs/04-calcs/01-sizing.md` (CVC-CAL-001 v0.5) and `docs/04-calcs/sizing.py`; masses from model volumes, reach, recovery pull, fin shadow and profiling error.
- Bill of materials: `bom/bom.csv` (15 lines).
- Decisions: `docs/decisions/0003-design-for-construction.md` (CVC-DDR-003), with CVC-DDR-001 and CVC-DDR-002; open items in `docs/06-design-decisions.md` (CVC-DEC-001).
- Requirements: `docs/03-requirements.md` (CVC-REQ-001 v0.7).

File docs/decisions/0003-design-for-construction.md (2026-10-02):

---
doc_id: CVC-DDR-003
title: CulvertCrawl design for construction
project: CulvertCrawl
doc_type: Design decision record
version: "0.3"
status: Draft
date: '2026-10-02'
author: Amish Chadha
license: CERN-OHL-S-2.0
revisions:
- version: "0.1"
  date: '2026-09-30'
  author: Amish Chadha
  change: Changes that make the concept physically buildable, with the reason for each; made under Amish's 2026-09-30 instruction to make the design physically buildable; open for his review
- version: "0.2"
  date: '2026-10-01'
  author: Amish Chadha
  change: Budget treated as a value-engineering target
- version: "0.3"
  date: '2026-10-02'
  author: Amish Chadha
  change: 'Accepted by Amish on 2026-10-02, including the recommendations for A2 to A4'
---

# 0003: Design for construction

- **Date:** 2026-09-30
- **Status:** accepted. Amish, 2026-10-02: "i approve your recommendations for all 555 open decisions." This covers every change in Tables 1 and 2 and the recommendations for A2 to A4 in Table 3, now decided as recommended and recorded in the design decisions register (CVC-DEC-001).

## Context

On 2026-09-30 Amish asked for every repo to have an illustrated build plan that shows how each component is made and how it fits the next, and wrote: "If you are realising that the design cannot be built as per concept - fix the design assumptions to match and be physically feasible as you draw the illustrations." The concept model of CVC-DDR-002 showed what CulvertCrawl does, but checking it with build123d found parts that overlapped, parts with no fixing, and parts that could not be made as drawn. Table 1 lists them (P1 to P14) and what was done about each.

The changes keep what CulvertCrawl does: the same 240 x 88 x 74 mm hull, the same 170 mm width over the tracks and 106 mm height, the same camera axis, dome and fisheye camera, the same laser ring 300 mm ahead of the dome centre, the same 48 V tether, surface battery, fuses and emergency stop, and the same reel and surface box sizes. Nothing here changes the pitch or the safety case. Every change is in `cad/src/model.py`, which now runs 94 constructability checks (`python cad/src/model.py --check`): parts that must touch do touch, and parts that must stay apart do so by at least the stated clearance. All 94 pass.

## Decision

*Table 1. Changes made to the model, the BOM and the calculations.*

| # | Problem in the concept | Change made | Why this way |
| --- | --- | --- | --- |
| P1 | The lid overhung the 4 mm walls by 3 mm and had nothing to seal on or screw into: a 4 mm wall cannot carry both an O-ring groove and a tapped hole. | The hull is machined from a solid block with a rim 12 mm wide and 10 mm deep inside the top. The lid O-ring sits in a groove in the rim top (8.3 to 10.7 mm in from the outside); ten M4 screws go into the rim outside the O-ring line. The lid is now flush, 240 x 88 x 6 mm, with an M10 pressure-test plug. | A face seal inside the screw line keeps every screw hole outside the sealed space. The rim still leaves a 64 mm opening for the tray to pass. |
| P2 | The track side plates (3 mm, inside each belt) overlapped the hull walls by 2 mm, the belts ran 1 mm from the hull, and the plates had no fixing. | Belts narrowed from 40 to 36 mm with the same outer edge (85 mm from the centre line), so the width over the tracks, the contact geometry in a round pipe and every fit calculation are unchanged. A made 3 mm side plate lies flat on each hull side and ballast side, 2 mm from the belt. | The plate needs a 3 mm gap that the concept did not leave; moving the outer edge would have changed R1 and the reach figures. |
| P3 | The gearboxes passed 3 mm through the rear wall and touched the tether gland; nothing held the motors; the shafts had no seal housing. | Gearboxes sit 2 mm inside the rear wall with their output shafts 14 mm from their rear ends. Each output face sits on a 6 mm drive pad inside the side wall and is held by two M4 countersunk screws that pass through the side plate, the wall and the pad. A 16 mm counterbore in the wall's outside face holds an 8 x 16 x 5 mm double lip seal, kept in by the side plate. Small O-rings under the side plate seal the two screw holes. | The motor is fixed by its own tapped output face; the side plate does three jobs (track guard, seal retainer, screw head bearing face). |
| P4 | The 48 to 12 V converter block sat inside the motor cans; the electronics floated. | A 2 mm aluminium tray on four floor pads (M3 screws). The Pi 4 sits on 4 mm spacers; a deck on 20 mm standoffs above it carries the motor driver, the converters and the IMU. | Uses the Pi's own mounting holes; the tray is the heat path to the floor. |
| P5 | The camera sat behind a solid front wall with no fixing. | Front wall 10 mm thick with a 50 mm bore; a printed camera mount screwed to its inside face holds the board so the lens centre is at the dome centre. | The thicker wall carries the bezel screws and the dome O-ring groove. |
| P6 | The dome flange overlapped the lid lip and had no clamp; the 88 mm LED ring board floated in front of the hull. | A machined aluminium front bezel (new BOM line 14) clamps the dome flange on an O-ring with four M4 screws. Eight stock 1 W LEDs on 10 mm boards sit in pockets in its face and are potted; their leads and the laser's enter the hull through a 5 mm potted hole in the front wall. LED positions are 22.5 degrees off the vertical so none sits where the fin passes. | Stock LED boards; the bezel is also the LEDs' heat sink. Same 88 mm envelope and 106 mm height. |
| P7 | The laser boom started at the tip of the dome, touching it at a point, with no fixing and no path for the laser wires. | The boom is solvent-welded along the top edge of an 8 mm clear acrylic fin. The fin bolts with two M3 bolts to an aluminium angle bracket screwed to the nose of the ballast plate. The laser wires run down the fin's back edge. The boom starts 7 mm in front of the dome. | The fin lies in a vertical plane through the camera axis, so the camera sees it edge on; it hides 6.4 % of the ring in a 300 mm pipe and 2.1 % in a 900 mm pipe, all at the invert. Re-running the profiling Monte Carlo with the fin in place gives 0.25, 0.57 and 0.97 % of diameter at 300, 600 and 900 mm (CVC-CAL-001 v0.5): R5 is still met. |
| P8 | The cone mirror sat bare beyond the diode housing with nothing holding it. | A clear acrylic window tube and an aluminium end cap: the mirror is bonded to the cap, the window joins cap and housing, and the ring leaves through the window wall. The ring plane stays 300 mm ahead of the dome centre; the crawler is 1 mm longer (611 mm). | This is the window and end cap the appearance model proposed on 2026-09-26 (review item 1); construction needs it. |
| P9 | The ballast plate had no fixing; its turned-up lip (bending 14 mm steel) is press work, not a small-shop job, and it ran into the LED ring. | Plate 255 x 88 x 14 mm with a square nose: as wide as the hull so the side plates screw into tapped holes in its sides, and 25 mm longer at the rear for the eye bolt. About 2.45 kg (was 2.13 kg). | The side plates now tie the hull to the ballast; no hole goes through the hull floor. |
| P10 | The tether's strength member had no anchor (only the gland), and the gland collided with the gearboxes. | An M8 forged eye bolt in the rear of the ballast plate takes the aramid strength member; an M10 IP68 penetrator in the rear wall, 77 mm above the contact line (was on the camera axis at 62 mm), seals the cable and sits between the gearboxes and the rim. | Recovery pulls go to the steel plate, not to a seal. |
| P11 | The idler axle had nothing to screw into. | An M6 shoulder bolt through the idler and the side plate into a blind tapped boss inside the hull wall (2 mm of metal left). | No through hole; the belt kit's 200 mm centres set the tension. |
| P12 | Reel: the A-frame tubes clashed with the flanges; the axle had no bearings; the drum was not fixed to the flanges or the axle; the slip ring body was free to turn. | Two 6 mm aluminium side frames on three spacer tubes and M6 tie rods; two 20 mm flanged bearings; a hollow 20 mm axle (the tether's inner end runs through it to the slip ring); a 225 mm PVC drum clamped between two 6 mm HDPE flanges by four M6 tie rods; a shaft hub bolted to each flange; a crank; an M8 knob brake on the left frame; a bracket that stops the slip ring stator turning. | Every part is cut from plate, pipe or tube or bought; the 320 mm reel size is kept. |
| P13 | The payout counter floated in the air in front of the reel, and its encoder had nothing to read it. | A bar clamped between the two halves of the front spacer carries the counter; a small USB encoder reader in the counter sends the count to the laptop. | The appearance model's counter bracket (review item 4), made buildable. |
| P14 | Surface box: the battery block was taller than the case and nothing inside was fixed. | A drop-in chassis: a 6 mm plywood base board, four aluminium posts and a 2 mm aluminium panel. The battery lies on its side, strapped to the base board; the converter and monitor screw to it; the stop, fuses and connectors are on the panel, which the lid closes over with 19 mm to spare. | The bought case is not drilled, so it stays waterproof, and the whole chassis lifts out. |

*Table 2. Knock-on changes.*

| Item | Change | Reason |
| --- | --- | --- |
| Mass | Crawler 6.63 kg (was 5.77 kg), 3.77 kg net when submerged (was 3.05 kg); hull and lid 1.26 kg and ballast 2.45 kg from model volumes. Kit 22.2 kg (was 18.1 kg); heaviest item the reel with tether, 7.8 kg. R10 still met. | Rim, pads, thicker front wall, wider and longer ballast plate, side plates, bezel; reel frames and box chassis. |
| Reach | Wet uphill 75 m (was 52 m); dry uphill 64 m; 23 m if submerged track friction is 0.45 (was about 10 m). Sprocket torque at the traction limit 0.84 N·m, within the 1 N·m motor rating. Locked-track recovery pull 59 N, factor 17 on the 1 kN tether. | Heavier crawler. |
| Profiling | 0.25, 0.57 and 0.97 % of diameter at 300, 600 and 900 mm, with the fin's shadow modelled. | P7. |
| Cost | BOM 15 lines, $1,034 against the $910 value-engineering target (`budget_usd`): $124 over. R12 is over the target. `budget_usd` is not changed; cost drivers and savings are in the Value engineering section of the design decisions register. | Parts added for construction: bezel (line 14), side plates and small made parts (line 15), reel frame, bearings and counter reader (line 10, $125 to $168), box chassis (line 11, $185 to $205), hull machining (line 1, $70 to $78), laser fin, window and cap (line 7, $47 to $55), ballast (line 8, $18 to $22), deck (line 4, $110 to $113), eye bolt and screws (line 13, $30 to $40). |
| Drawings | CVC-DWG-001 Rev P3; making sketches CVC-DWG-101 to 119; concept blueprint CVC-DWG-010 Rev P2. | Follow the model. |
| Documents | CVC-CAL-001 v0.5, CVC-REQ-001 v0.7, CVC-PRC-001 v0.7. | Follow the model. |
| Thermal and power | Unchanged: the same loads, tether and battery. | |

*Table 3. Proposed, then accepted by Amish as recommended on 2026-10-02.*

| # | Question | Options | Recommendation |
| --- | --- | --- | --- |
| A2 | The boom is now held by two M3 bolts at the fin bracket, so it can come off for repair. Whether it should be quick-release in the field is the open removable-boom question (CVC-DDR-002, item 6). | (a) keep the two bolts; (b) a tool-free clamp at the bracket. | (a) for the prototype; decide (b) after the first pipe trials. |
| A3 | The fin hides a strip of the ring at the invert (6.4 % of the ring in 300 mm pipe). In a dry pipe the lowest wall point is not measured; the water or sediment chord is still seen at both ends. | (a) accept; (b) move the fin off the vertical to one side. | (a): the ellipse fit and R5 are unaffected, and the invert is usually under water or silt. |
| A4 | The crawler is 0.86 kg heavier. This helps reach but raises motor torque at the traction limit from 0.73 to 0.84 N·m against the 1 N·m rating. | (a) accept; (b) thin the ballast plate to 12 mm to hold the concept mass. | (a): the margin on reach is the thinnest in the design, and the motor is still within its rating. |

## Consequences

- `design_state: constructable` in `project.yaml`. The build plan CVC-BLD-001 shows every component and step in pictures generated from the model (`cad/src/build_plan_media.py`); the open items are in the design decisions register CVC-DEC-001.
- Cost is reported against the value-engineering target: USD 910 (a hypothetical control target, not a limit) against an estimated USD 1,034 for the constructable design, USD 124 over. Savings worth trying (a bought cable reel, a printed bezel, a smaller case) are in the register.
- Requirement status (CVC-CAL-001 v0.5): 1 over its value-engineering target (R12, cost), 2 at risk (R7, R8), 1 not verifiable at TRL 3 (R6), 9 met on paper (R1, R2, R3, R4, R5, R9, R10, R11, R13); R5 at 900 mm keeps its thin margin.
- The photoreal renders (`media/render-*.png`), `media/card.png`, `media/social-preview.png` and the appearance model `cad/src/product_model.py` still show the concept lid lip, LED ring, bare cone and reel frame; they need updating on Amish's Mac, where Blender is.
- With A2 to A4 accepted: the boom stays on two M3 bolts for the prototype and a tool-free clamp is decided after the first pipe trials; the fin's shadow at the invert and the 6.63 kg crawler are accepted.
- Shaft length, gearbox face holes, the belt kit's tension at 200 mm centres, the slip ring and the case's inside size are checked when parts are bought (register, "To confirm").

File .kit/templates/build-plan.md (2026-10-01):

---
doc_id: PRJ-BLD-001
title: Project prototype build plan
project: Project name
doc_type: Build plan
version: "0.1"
status: Draft
date: YYYY-MM-DD
author: Amish Chadha
license: CERN-OHL-S-2.0
revisions:
  - version: "0.1"
    date: YYYY-MM-DD
    author: Amish Chadha
    change: First build plan; design made constructable
---

# Project prototype build plan

**Plan, not yet built.** How to build the first proof-of-concept prototype, component by component. Building and testing to it is TRL 4 work. Decisions still to be made are kept in the design decisions register (`docs/06-design-decisions.md`), not here.

## 1. What you are building

Every component, pulled apart and numbered in build order

One short paragraph: what the prototype is, how many components, which are made and which are bought, and the main ways they are made.

## 2. What changed to make it buildable

| Component | The concept had | The buildable design has | Why |
| --- | --- | --- | --- |

## 3. Making the components

### 3.1 Component name

Making sketch

**What it is and what it is made from.**

**How to make it.**

1. Mark out ...
2. Cut ...

**How it fits the parts next to it.**

Close-up of the joint

**Check before moving on.**

## 4. Putting it together

### Step 1: ...

Step 1

## 5. First checks

| Check | Requirement | How | Pass when |
| --- | --- | --- | --- |

## 6. Safety stops

## 7. Tools, skills and workspace

## 8. Where the numbers come from

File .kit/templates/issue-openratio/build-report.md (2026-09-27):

---
name: Build report
about: Tell us what happened when you built, printed or tested part of this design
title: "Build report: "
labels: build-report
---

This is a research and educational prototype, not a medical device. It is a TRL 3 concept and is not released for fabrication. If you build any part of it, you do so at your own risk. Reports help everyone.

**What you built** (part, sub-assembly or test)

**Materials, tools and settings**

**What worked**

**What did not work, with photos or measurements if you have them**

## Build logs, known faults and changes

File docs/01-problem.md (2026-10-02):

---
doc_id: CVC-PRB-001
title: CulvertCrawl problem statement
project: CulvertCrawl
doc_type: Problem statement
version: "0.8"
status: Draft
date: '2026-10-02'
author: Amish Chadha
license: CERN-OHL-S-2.0
revisions:
- version: "0.1"
  date: '2026-09-24'
  author: Amish Chadha
  change: Initial scaffold
- version: "0.2"
  date: '2026-09-25'
  author: Amish Chadha
  change: Populate to TRL 2 (users, context, current practice, constraints, out of scope, prior work)
- version: "0.3"
  date: '2026-09-25'
  author: Amish Chadha
  change: TRL 3. Record Amish's 2026-09-25 decisions (CVC-DDR-001) on budget and pipe range; citation check
- version: "0.4"
  date: '2026-09-25'
  author: Amish Chadha
  change: Recommendations accepted by Amish (DDR-002)
- version: "0.5"
  date: '2026-09-26'
  author: Amish Chadha
  change: Budget approved by Amish ($910, CVC-DDR-002)
- version: "0.6"
  date: '2026-09-30'
  author: Amish Chadha
  change: Priced BOM restated after the design for construction (CVC-DDR-003)
- version: "0.7"
  date: '2026-10-01'
  author: Amish Chadha
  change: Budget treated as a value-engineering target
- version: "0.8"
  date: '2026-10-02'
  author: Amish Chadha
  change: 'Open questions on the first partner and the output order answered by the decisions of 2026-10-02 (CVC-DEC-001)'
---

# CulvertCrawl problem statement

Small road culverts and storm drains, roughly 300 to 900 mm (12 to 36 in) across, are too small or too hazardous to walk through, so most of them are judged from the two ends with a flashlight. Commercial CCTV crawlers that can see and measure the inside cost tens of thousands of dollars (estimate) and are held by sewer contractors, not by the county road crews, small municipalities and watershed groups who own or survey most small culverts. CulvertCrawl is an open, garage-buildable tethered crawler that drives into the pipe, records video and measures the pipe's cross-section with a projected laser ring, so the owner can see deformation, corrosion and blockage without anyone entering the pipe.

## The problem

Culverts carry streams and runoff under roads, driveways, farm tracks and rail lines. Their failure modes develop out of sight: corrugated metal pipe rusts through at the invert, plastic pipe deflects out of round under load, joints separate and pull in soil, and sediment and debris build up until the pipe floods the road or washes out. The FHWA *Culvert Assessment and Decision-Making Procedures Manual* (FHWA-CFL/TD-10-005, 2010) rates barrel condition on exactly these features, and the older FHWA *Culvert Inspection Manual* (FHWA-IP-86-2, 1986) notes that small barrels usually have to be inspected from the ends.

Seeing the inside of a small culvert is hard for three reasons:

1. **Entry is dangerous or impossible.** A culvert is a confined space: it has limited entry and exit and is not designed for occupancy. Where it can hold a hazardous atmosphere, engulfment by water or silt, or a configuration that traps a person, it is a permit-required confined space under OSHA 29 CFR 1910.146 ([osha.gov](https://www.osha.gov/laws-regs/regulations/standardnumber/1910/1910.146)), or under 29 CFR 1926 Subpart AA in construction work, which needs an entry permit, atmospheric testing, an attendant and a rescue plan. Pipes under about 900 mm are too small for practical entry.
2. **End views miss the middle.** From the ends, an inspector sees a few meters in. A 20 to 40 m road crossing can hide a rusted-through invert, a collapsed joint or a blockage in its middle.
3. **Existing robots are expensive and specialized.** Sewer CCTV crawlers (for example the Envirosight ROVVER X, CUES and iPEK systems) do this job well, and some offer laser or multi-sensor profiling, but they are priced and supported for utility contractors. Hiring a CCTV contractor for one culvert costs several hundred to a few thousand dollars per visit (estimate), so small owners rarely do it until a failure forces the issue. Plumbers' push cameras are cheap but cannot drive, do not light a 600 mm pipe well and do not measure anything.

The missing piece is a measurement, not only a picture. Plastic pipe acceptance is judged by deflection: ASTM D2321 installation practice and state DOT specifications that follow AASHTO commonly limit installed deflection of thermoplastic pipe to about 5 % of the inside diameter, checked with a mandrel or a laser profiler. The same ring measurement shows the sag of a failing metal pipe and the depth of sediment in any pipe.

## Users and context

| User | Need | Context |
| --- | --- | --- |
| County or township road crew | Check road culverts before resurfacing, after floods and when a sinkhole appears, without calling a contractor | Two-person crew with a pickup truck, roadside ditch, traffic nearby |
| Small municipality public works | Inventory storm drain and culvert condition to plan replacements within a small budget | Mixed concrete, metal and plastic pipes, 300 to 900 mm |
| Consulting or DOT inspector | Measure deflection of newly installed plastic pipe and document defects with location | Acceptance inspection, needs a repeatable number and a report |
| Watershed or fish-passage survey group | Check culverts for blockage, perched outlets and internal barriers to fish | Rural streams, volunteers, wading access, limited funds |
| Farm, estate, rail or trail owner | See why a driveway or trail culvert floods | Occasional use, no inspection training |
| Maker or student team | Build, repair and extend an open inspection robot | Garage tools, hobby electronics |

### Operating environment

- **Pipes:** round culverts of 300 to 900 mm (12 to 36 in) inside diameter; corrugated steel or aluminium, reinforced concrete, and corrugated or smooth-wall HDPE and PVC. Straight runs of 10 to 50 m are typical of road crossings; slopes are usually a few percent.
- **Inside the pipe:** dark; standing or flowing water, often 0 to 150 mm deep; silt, sand, gravel, branches and litter; rust scale and sharp edges at holes and joints; possible wildlife.
- **At the mouth:** steep, wet ditch banks; riprap; headwalls; often a road shoulder with passing traffic.
- **Climate:** 0 to 40 °C ambient, rain and mud; equipment carried by hand from a vehicle.
- **Atmosphere:** culverts carrying streams are usually open to air, but storm drains and long or blocked pipes can hold low oxygen, hydrogen sulfide or methane. CulvertCrawl is not designed for flammable atmospheres (see the precis, CVC-PRC-001).

## Constraints

- Garage-buildable prototype, with a value-engineering target of $910 USD in parts (`project.yaml`; a hypothetical control target, not a limit; set at $800, then $900 by Amish on 2026-09-25, CVC-DDR-001, and $910 on 2026-09-26 to match the priced BOM, CVC-DDR-002). The estimated cost was $906 (CVC-CAL-001 v0.3); after the design for construction it is $1,034 (CVC-CAL-001 v0.5), $124 over the target (CVC-DDR-003).
- No person enters the pipe at any stage, including recovery of a stuck crawler.
- Safe extra-low voltage only in the tether and crawler (48 V DC or less), and an eye-safe laser (Class 2 or lower) so the tool can be used by non-specialists.
- Carried by two people from a vehicle to a ditch in one trip, and set up in minutes.
- Open hardware (CERN-OHL-S-2.0) and open software (MIT), common hobby and industrial parts, and open data formats for video, profiles and observation logs.
- Observations recorded so they can be mapped to established defect codes such as the NASSCO Pipeline Assessment Certification Program (PACP, [nassco.org](https://www.nassco.org)), without claiming PACP certification.

## Out of scope

- Sanitary sewers, gas-bearing drains or any location where a flammable atmosphere may be present. The crawler is not intrinsically safe or ATEX rated.
- Pipes under 300 mm or over 900 mm, non-circular box culverts and arches (possible later variants).
- Cleaning, cutting roots or clearing blockages.
- Lateral launch, steerable camera heads with pan and tilt, sonar for full pipes, and GIS asset management software.
- Structural rating or load capacity decisions. CulvertCrawl measures shape and records condition; a qualified engineer rates the structure.

## Prior work

- **Commercial sewer CCTV crawlers.** Envirosight (ROVVER X), CUES, iPEK (ROVION) and RedZone Robotics build tethered crawlers with lights, pan-tilt cameras and, as options, laser profiling, sonar and payout counters. They set the functional benchmark and show that ring laser profiling works in practice, but cost and support model put them out of reach of small culvert owners.
- **Laser ring profiling research.** Duran, Althoefer and Seneviratne reviewed sensors for sewer inspection ("State of the art in sensor technologies for sewer inspection," *IEEE Sensors Journal* 2, no. 2, 2002) and later used a camera and ring laser profiler with a neural network to detect and classify pipe defects (*IEEE Transactions on Automation Science and Engineering* 4, no. 1, 2007). This is the measurement principle CulvertCrawl uses.
- **Open underwater ROVs.** OpenROV (2012 onward) and Blue Robotics' BlueROV2 with its Fathom tether show that a small open vehicle can stream video and control over a thin tether to a laptop, and that hobby parts can be sealed well enough for real field work.
- **Push cameras and borescopes.** Plumbing push cameras (fiberglass rod, 20 to 60 m) are cheap and widely owned but have no drive, weak lighting for 600 mm pipe and no measurement.
- **Defect coding.** NASSCO PACP gives a common vocabulary for pipe defects (deformation, cracks, joints, deposits, obstructions), and the FHWA culvert manuals give condition ratings for culvert barrels.

Sources were checked online on 2026-09-25 where possible: the OSHA 1910.146 title and confined-space definition (osha.gov), FHWA-IP-86-2 (1986) and FHWA-CFL/TD-10-005 (2010) by their FHWA and TRB catalog entries, and both Duran, Althoefer and Seneviratne papers by title and journal (the 2007 paper at volume 4, page 118). The ASTM D2321 deflection clause, the NASSCO PACP page and the product pages were not rechecked.

## Open questions

- Who is the first user group for field trials (a county road department, a watershed group or a university transportation program)? Decided 2026-10-02 (CVC-DEC-001): a county road department, with a university transportation program as backup; the first candidate to approach for the backup is the Texas A&M Transportation Institute.
- The pipe range stays 300 to 900 mm (decided by Amish, 2026-09-25). With the ring plane moved to 300 mm ahead (CVC-DDR-002), CVC-CAL-001 v0.2 shows R5 met at 900 mm with a thin margin (0.97 %); users should say how often 900 mm pipes need an acceptance-grade number.
- What reach is needed? 50 m is assumed from typical two-lane and four-lane road crossings; to validate with users.
- Is an acceptance-grade deflection number (for new plastic pipe) needed, or is condition screening enough? This sets the profiling accuracy requirement.
- Should the tool produce a PACP-style report, the FHWA condition ratings, or both? Decided 2026-10-02 (CVC-DEC-001): the deflection report first, observations in NASSCO PACP vocabulary second, FHWA condition ratings later.
- From which end do crews usually enter a culvert? CVC-CAL-001 v0.2 shows reach depends strongly on direction (52 m uphill against flow, more than 90 m downhill); entering flooded pipes from the upstream end is now operating guidance (CVC-DDR-002).

## User research and co-design

- [ ] Identify one or two partner users (road crew, watershed group or inspector) willing to review the concept
- [ ] Walk three to five real culverts with them and record pipe sizes, lengths, water depth, debris and access
- [ ] Validate reach, pipe range, accuracy and cost assumptions
- [ ] Revise requirements (CVC-REQ-001) from findings before freezing the design

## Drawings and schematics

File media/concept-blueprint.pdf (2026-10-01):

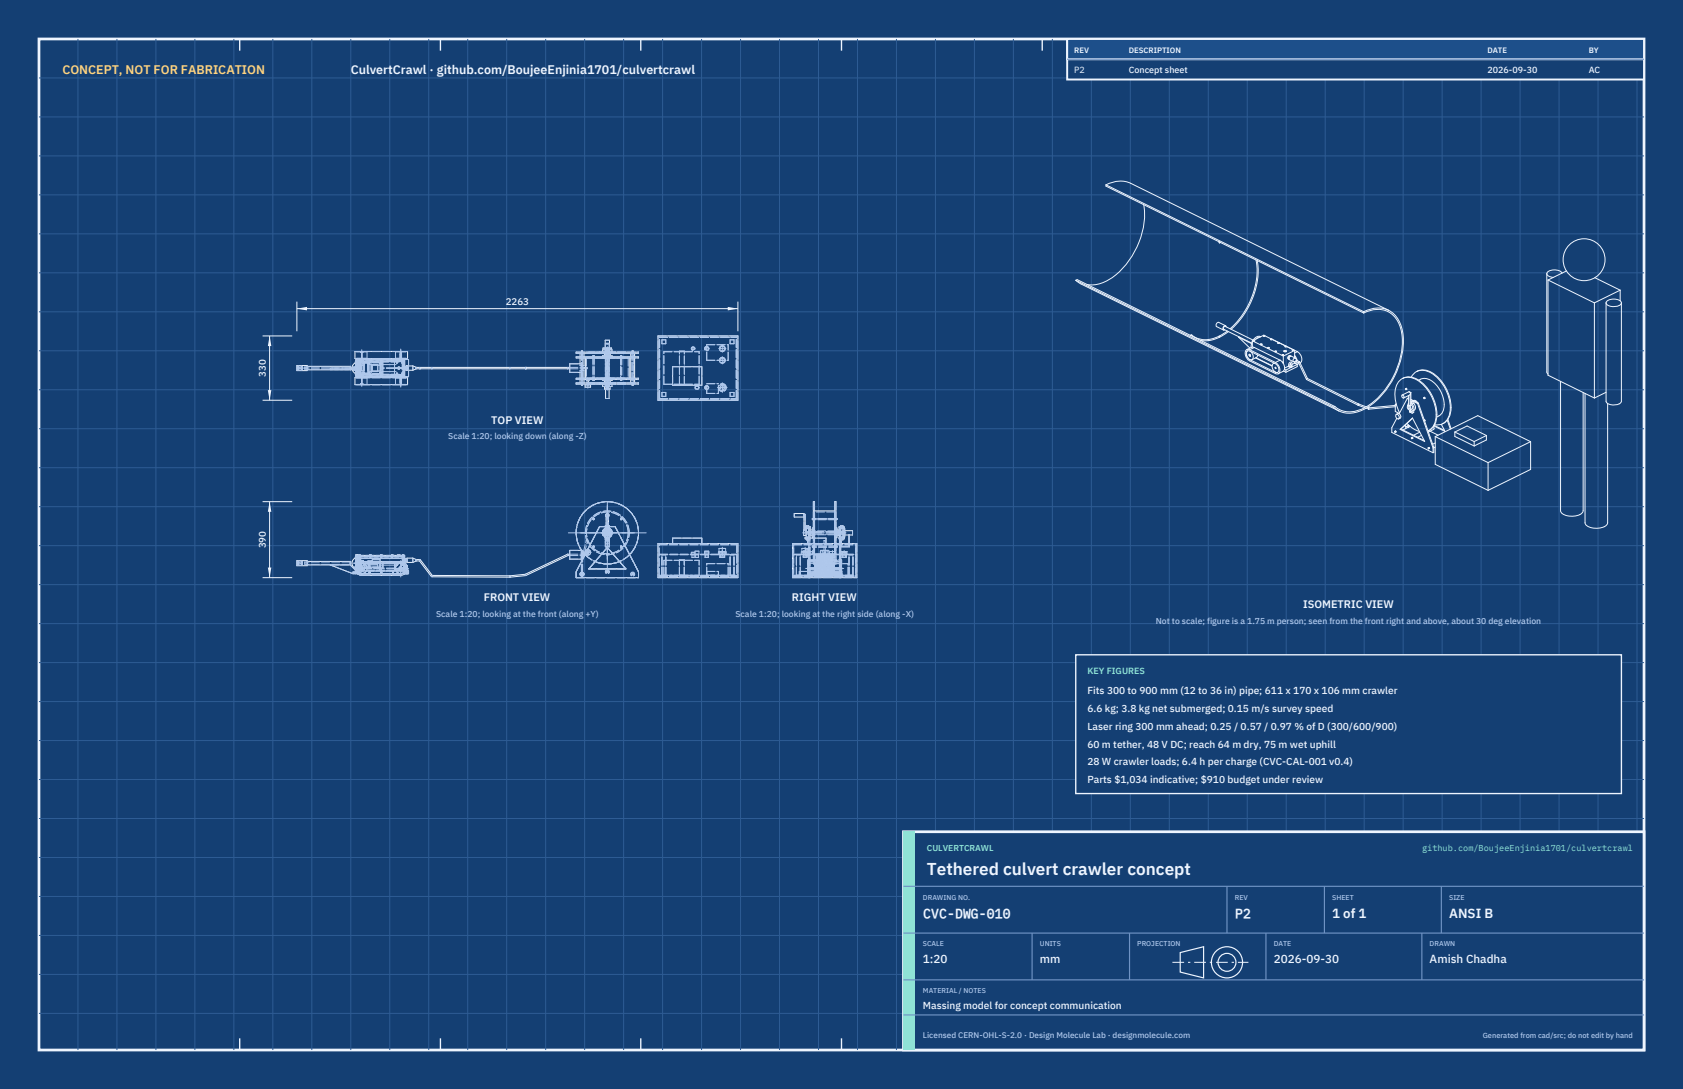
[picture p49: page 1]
CONCEPT, NOT FOR FABRICATION; CulvertCrawl · github.com/BoujeeEnjinia1701/culvertcrawl; FRONT VIEW; TOP VIEW; RIGHT VIEW; ISOMETRIC VIEW; REV; DESCRIPTION; DATE; Concept sheet; CULVERTCRAWL; github.com/BoujeeEnjinia1701/culvertcrawl; DRAWING NO. CVC-DWG-010; REV P2; SHEET 1 of 1; SIZE ANSI B; SCALE 1:20; UNITS mm; PROJECTION; DRAWN Amish Chadha; Licensed CERN-OHL-S-2.0 · Design Molecule Lab · designmolecule.com; Generated from cad/src; do not edit by hand

Scale 1:20; looking down (along -Z)

Scale 1:20; looking at the front (along +Y)

Scale 1:20; looking at the right side (along -X)

Not to scale; figure is a 1.75 m person; seen from the front right and above, about 30 deg elevation

KEY FIGURES
Fits 300 to 900 mm (12 to 36 in) pipe; 611 x 170 x 106 mm crawler
6.6 kg; 3.8 kg net submerged; 0.15 m/s survey speed
Laser ring 300 mm ahead; 0.25 / 0.57 / 0.97 % of D (300/600/900)
60 m tether, 48 V DC; reach 64 m dry, 75 m wet uphill
28 W crawler loads; 6.4 h per charge (CVC-CAL-001 v0.4)
Parts $1,034 indicative; $910 budget under review

Tethered culvert crawler concept

MATERIAL / NOTES
Massing model for concept communication

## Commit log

2026-09-24 Initial scaffold: standard open hardware layout, CERN-OHL-S v2 + MIT licenses
    Claude-Session: https://claude.ai/code/session_01XuhhSU4W6fYhgCfURbrkut
    [bom.csv]
2026-09-25 Adopt portfolio kit v1.3.0: session commands, scale figure, 3D viewer, flow diagrams
    Adds .claude/commands (/populate, /advance-trl3, /rein-in, /refresh-media)
    so every Claude Code session starts from the standard prompts, and extends
    concept media with a 1.75 m scale figure, an interactive glTF viewer and
    system or energy flow diagrams. TRL cap 3 unchanged.
    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
2026-09-25 Kit v1.3.1: renderer fixes from the TremorTrace pilot
    Context scale parts for small objects, cutaway exclusions, and text
    labels in flow diagrams.
    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
2026-09-25 Populate culvertcrawl to a strong TRL 2 with concept media (batch 7)
    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
    [bom.csv]
2026-09-25 Advance culvertcrawl to TRL 3 (batches 7 and 8)
    Decisions approved by Amish 2026-09-25 recorded in DDR-001. TRL 4 is on hold.
    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
    [bom.csv, culvertcrawl-crawler.step, culvertcrawl-crawler.stl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]
2026-09-26 Accept all recommendations (DDR-002), switch footer to designmolecule.com, add README write-up with new inspiration point
    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
    [bom.csv, culvertcrawl-crawler.step, culvertcrawl-crawler.stl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]
2026-09-26 Strengthen sources, apply approved budgets, add CITATION.cff and CONTRIBUTORS.md with credits
    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
    [results.csv]
2026-09-27 Product appearance model and photoreal renders
    Adds cad/src/product_model.py (appearance model for renders only, all main
    dimensions from model.py) and Blender renders in media/render-*.png,
    captioned with the project, repository and viewing direction. README leads
    with the product render; trl stays 3.
    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
2026-10-01 Image quality pass: legible exploded views, flow diagrams and drawing sheets
    Kit 1.6.1 image layout: the parts list sits in its own column, number bubbles sit on visible parts and never overlap, small parts get a leader, pictures are cropped to the subject, flow labels keep numbers with their units, and sheet captions and the revision table no longer overprint. Concept images, blueprint and general arrangement sheet regenerated; repo-specific labels moved clear of other text and lines.
2026-10-01 Kit 1.7.0: constructable design, illustrated build plan and design decisions register
    The design is now constructable: every part can be made and fits its neighbours, with each change recorded in a Design for construction decision record (made under Amish's 2026-09-30 instruction; ope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
    [bom.csv, culvertcrawl-crawler.step, culvertcrawl-crawler.stl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]
2026-10-01 Budget treated as a value-engineering target
    Amish, 2026-10-01: the budget is a hypothetical control target that keeps the design on a value-engineering lens, not a spending limit. Documents now state the value-engineering target and the estima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
2026-10-02 Record Amish's approval of the open-decision recommendations
    Amish approved the recommendation on every open decision in the design decisions register ("i approve your recommendations for all 555 open decisions.", 2026-10-02). Each decision is moved to Decisio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
2026-10-03 Carry approved follow-ups into the design and redo photoreal renders
    Amish approved the follow-up actions from the open-decision sign-off ("APPROVED CHANGES, COMPLETE THESE", 2026-10-02), the design-for-construction change tables in ten repos, the last wave's open dec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
